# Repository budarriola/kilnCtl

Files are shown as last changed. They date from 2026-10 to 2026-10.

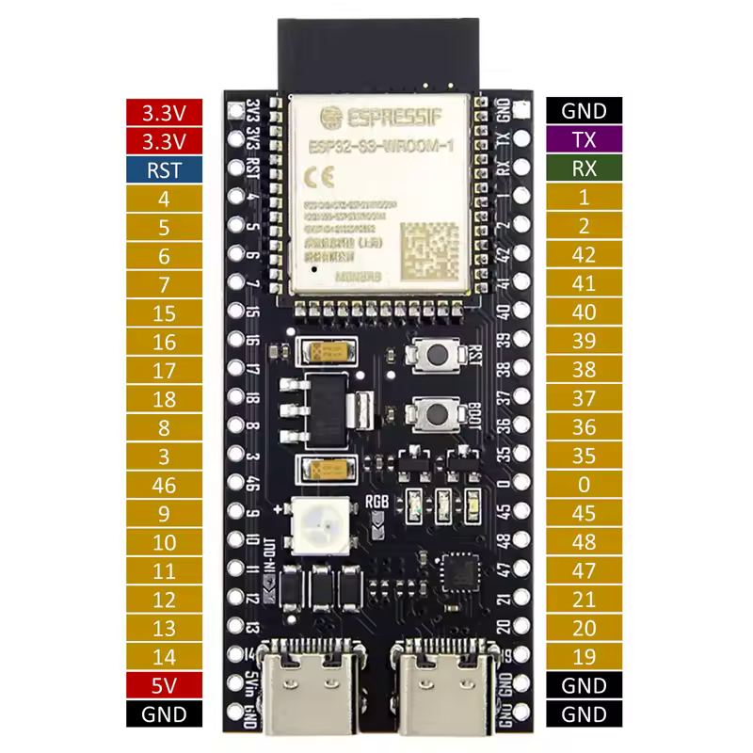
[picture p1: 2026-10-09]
tools/PcTools/src/kilnctrl/assets/pinout.png

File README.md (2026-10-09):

# kilnCtl

> **WARNING: read the [Liability waiver and safety disclaimer](#liability-waiver-and-safety-disclaimer)
> before you build, flash, wire, or power anything from this repository.**
> This is an unfinished, experimental controller for an appliance that runs above
> 1000 °C on mains power. Even where it is believed to be stable, assume it **will**
> start a fire that burns your house down with everyone inside it.

A kiln controller: three KiCad boards, two independent firmwares, and the PC
tooling that drives both.

Heating is commanded by an ESP32-S3 through solid-state relays. A separate
RP2040 watches the same kiln and can cut power through a mechanical pilot relay
that is wired in series with the contactor coil. The two processors talk over an
opto-isolated UART, and the main processor is not allowed to heat unless the
safety processor is answering.

## Start here

**[ROADMAP.md](ROADMAP.md)** is the top-level plan across both processors. It
holds the milestone order and the cross-processor dependencies, and links to the
plan that owns each area. If you do not already know which document covers what
you are about to do, start there.

## Running the regression suite

```
python tools/regression_suite.py
```

One command, every automated gate this repo has, one pass/fail summary and a
non-zero exit on any failure (usable in CI or a pre-commit hook). It runs, in
order: `tools/run_all_checks.ps1` (the mechanical `check_*.ps1` guards, plus
the JS/browser harnesses and the headless-Chrome responsive sweep, which are
themselves wired into that script's discovery); then, in parallel, the KilnFW
and SaftyFW off-target host-test suites and the `tools/PcTools` pytest suite
(its live-bench tests self-skip with no board attached); then,
in parallel, the two target firmware *compiles* (KilnFW over ESP-IDF, SaftyFW
over pico-sdk -- no flashing, ever). One gate failing does not stop the
others; the final summary lists every gate's pass/fail and points at the full
log for anything that failed. See the script's own header comment for why
each stage is grouped and parallelized the way it is.

## Opening this repository

On a fresh clone, run **[`tools/setup.ps1`](tools/setup.ps1)** first — it
discovers where ESP-IDF, clangd and OpenOCD live on this machine and generates
the config files that cannot be committed. Full detail:
[docs/SETUP.md](docs/SETUP.md).

In VS Code, open **`kilnCtl.code-workspace`** rather than the `kilnCtl` folder.
The ESP-IDF extension treats a workspace folder as one project and needs a
`CMakeLists.txt` in it; the repository root does not have one. The workspace file
lists each firmware, `tools/PcTools` and `hardware` as folders in their own right,
and carries the shared tasks.

Shell commands in this repository are written to run from the root, so they carry
a path argument: `idf.py -C firmware/KilnFW build`,
`uv run --project tools/PcTools kilnctrl-gui`.

## Layout

```
hardware/   KiCad projects, shared library, datasheets, LTspice, sourcing
firmware/   KilnFW (ESP32-S3), SaftyFW (RP2040), CommonFW (shared)
tools/      PcTools - GUI and MCP server for both processors
docs/       System-level documents that span hardware and firmware
```

`mykicadMcp/` and `pdfMcp/` both moved under `tools/` 2026-08-28.
The rationale for the split, and what broke during it, is
[docs/REPO_LAYOUT.md](docs/REPO_LAYOUT.md).

## The three boards

| Board | What it is |
|---|---|
| `hardware/mainBoard` | ESP32-S3 controller, SSR drivers, current sense, isolated link, safety RP2040 |
| `hardware/ThermocoupleBoard` | 3-channel MAX31856 daughterboard |
| `hardware/SaftyThermocoupleBoard` | The safety processor's own thermocouple front end |

`Thermocouple.kicad_sch` appears in more than one project as a copy of the same
circuit, so a fix found in one usually applies to the others.

## The two firmwares

- **`firmware/KilnFW`** — ESP-IDF. Thermocouples, PID, profile execution, Wi-Fi
  provisioning, web UI. Partly built, partly verified on hardware; the honest
  ledger is [firmware/KilnFW/docs/PROJECT_STATUS.md](firmware/KilnFW/docs/PROJECT_STATUS.md).
- **`firmware/SaftyFW`** — pico-sdk and FreeRTOS SMP. Independent overheat and
  fault detection, owns the pilot relay. Planned in detail, **not yet built**.
- **`firmware/CommonFW`** — the link contract and its codecs, implemented once
  and linked by both. Also not yet built.

The safety processor's job is to catch faults, not to be sensitive: every trip
has to clear both a magnitude that correct operation cannot reach and a duration
a transient cannot sustain. That reasoning is
[firmware/SaftyFW/docs/SAFETY_MODEL.md](firmware/SaftyFW/docs/SAFETY_MODEL.md).

## Tooling

`tools/PcTools` is one GUI and one MCP server for both processors — serial to
the ESP, the isolated UART or SWD to the Pico, per-processor consoles and log
files. See [tools/PcTools/README.md](tools/PcTools/README.md) for what exists and
[tools/PcTools/TODO.md](tools/PcTools/TODO.md) for what is planned.

`mykicadMcp` is a separate submodule exposing KiCad inspection, sourcing and
autorouting over MCP.

## Bench setup

Programming, debug and console for the RP2040 all go through a Raspberry Pi
Debug Probe: SWD to the DEBUG pads, and the probe's UART bridge on GP16/GP17.
The Pico's own USB is deliberately not used. Wiring is
[firmware/SaftyFW/docs/HARDWARE.md](firmware/SaftyFW/docs/HARDWARE.md) §7b.

## Liability waiver and safety disclaimer

**This project is a work in progress. It is not finished, not certified, and not
safe.** Everything in this repository (schematics, PCB layouts, firmware for both
processors, PC tools, documentation, release images, and any advice in issues or
discussions) is an experimental, hobbyist development effort that is still
changing daily.

**Even where a part of it is believed to be stable, it is not.** Code that has
passed every test in this repository, every bench run, and every review can still
fail in the field. Treat every release, including those marked "stable", as a
pre-release prototype.

**Assume it will burn your house down with everyone inside.** A kiln is a
resistive heater that reaches well above 1000 °C, draws tens of amps from mains
power, and is often left unattended for many hours. A controller fault, a
firmware bug, a stuck or welded relay, a failed thermocouple, a wiring mistake, a
bad update, a power glitch, or a single misread value can leave the elements
energized with nothing to stop them. The likely result is a fire that destroys the
building and kills or seriously injures the people and animals inside it.
Electrocution, burns, toxic fumes, and damage to the kiln, its contents and
nearby property are also likely. Plan as if these outcomes will happen, not as if
they might.

**The safety processor does not make this safe.** The RP2040 safety processor, its
trip guards, the E-stop path, the pilot relay, and every other protective feature
described here are part of the same unfinished, unverified design. They have not
been independently evaluated and must not be relied on to prevent fire, injury or
death. This design does not replace a certified, independent over-temperature
cutoff, a correctly rated contactor, proper overcurrent protection, a
non-combustible installation, working smoke and fire detection, and a person
physically present and watching the kiln.

**No certification.** Nothing here has been tested, listed or approved by UL, CSA,
CE, TÜV, or any other safety or standards body, and nothing here complies with
any electrical, building or fire code. Installing it may break local law, void
your insurance, and void the kiln manufacturer's warranty. Mains wiring must be
done by a licensed electrician where your jurisdiction requires it.

**No warranty.** This project is provided "AS IS" and "AS AVAILABLE", without
warranty of any kind, express or implied. That includes, without limitation, any
warranty of merchantability, fitness for a particular purpose, safety, accuracy,
reliability, non-infringement, or that it will work at all.

**No liability.** To the fullest extent permitted by law, the authors,
contributors, copyright holders, and anyone who distributes this project are not
liable for any claim, damage, injury, death, loss of property, loss of data, loss
of income, or other loss of any kind, whether direct, indirect, incidental,
special, consequential, or punitive, and whether based on contract, tort
(including negligence), strict liability, or any other theory. This holds even if
they were told such loss was possible, and it applies to any use of this project,
any inability to use it, and any failure of it.

**You accept all risk.** By building, flashing, installing, operating, modifying,
or distributing anything from this repository, you agree that you do so entirely
at your own risk, that you are solely responsible for the safety of your
installation and of everyone and everything near it, and that you will indemnify
and hold harmless the authors and contributors against any claim arising from
your use. If you do not accept these terms, do not use this project.

**Not advice.** Nothing in this repository is professional, electrical,
engineering, or legal advice. If any part of this waiver cannot be enforced where
you live, the rest of it still applies.

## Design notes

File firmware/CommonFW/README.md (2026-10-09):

# CommonFW — shared control-interface code

> **Status:** planning · **Last reviewed:** 2026-08-24
> **Keep this file current.** If you change anything this document describes,
> update it in the same commit. If it disagrees with the code, **the code
> wins** — fix this file and say so in the commit message.

The wire between the ESP32-S3 main controller ([`../KilnFW`](../KilnFW)) and
the RP2040 safety processor ([`../SaftyFW`](../SaftyFW)), implemented **once**
and linked into both.

`CommonFW` also hosts a second, independent protocol family here:
**`benchproto`** ([`docs/BENCHPROTO.md`](docs/BENCHPROTO.md),
`include/benchproto/`, `src/benchproto_*.c`) — a hardened, addressed
request/reply protocol (framing, CRC16, retry/dedup, task registration) for
bench/instrument firmwares talking to a PC, extracted from
`firmware/UnitTestFw`'s UART prototype for SimFW's USB-CDC link (SimFW
was removed 2026-08-28, `UnitTestFw` restored in its place; the design
rationale that lived in SimFW's `docs/DESIGN_NOTES.md` sec 4.4/12 went with
it). It shares no code with `kilnlink`
— see `docs/BENCHPROTO.md` sec 1 for why the two look alike but are kept
apart — and is host-tested the same way (`test_benchproto_frame.c`,
`test_benchproto_link.c`, both wired into this file's `CMakeLists.txt`).

**Status: the framing layer exists and is host-tested.** `kilnlink_frame.{c,h}`
+ `kilnlink_crc.c` are written, byte-exact cross-checked against
`tools/PcTools/src/kilnctrl/protocol.py` (the second, already-proven
implementation of this exact envelope) via `test/vectors/frame_vectors.json`,
consumed by both `test/test_frame.c` (built and passing with MSVC via CMake +
Ninja, verified 2026-08-16) and `tools/PcTools/selfcheck.py`. **Framing is now
integrated into both firmwares** (as of 2026-08-18): `KilnFW`'s
`firmware/hwAbstraction/esp/uart/uart_protocol.c` calls `kilnlink_crc16_ccitt_false`/
`kilnlink_stuff` instead of its own copies, proven byte-identical against the
pre-migration implementation (`test/test_uart_protocol_delegate.c`); `SaftyFW`
now has a real CMake project (`firmware/SaftyFW/CMakeLists.txt`,
`add_subdirectory(../CommonFW kilnlink)`) linking `kilnlink` into all three of
its executables, and `link_task.c` calls into several of the payload codecs
directly (see below). Payload-codec migration is still partial — see
"2026-08-19" below and the Completion checklist's Migration section.

**2026-08-19: every command/frame `docs/LINK_PROTOCOL.md` sections 4 and 6 give
a concrete byte layout for now has a codec.** ESP→Pico (sec 4):
`kilnlink_context.{c,h}` (`SAFETY_CMD_PUSH_CONTEXT` 0x07, including
`relay_recent_mask` and the per-zone block), `kilnlink_announce.{c,h}`
(`SAFETY_CMD_ANNOUNCE_VERSION` 0x0F, the compatibility-floor layout),
`kilnlink_ceiling.{c,h}` (`SAFETY_CMD_SET_FIRING_CEILING` 0x09),
`kilnlink_clear_trip.{c,h}` (`SAFETY_CMD_CLEAR_TRIP` 0x0A),
`kilnlink_get_fw_version.{c,h}` (`SAFETY_CMD_GET_FW_VERSION` 0x0B, one byte,
no fields), `kilnlink_set_clock.{c,h}` (`SAFETY_CMD_SET_CLOCK` 0x0C, optional).
Pico→ESP (sec 6): `kilnlink_status.{c,h}` (Frame A, `SAFETY_CMD_GET_STATUS`
0x01, the existing 23-byte layout), `kilnlink_diag.{c,h}` (Frame B,
`SAFETY_CMD_DIAG` 0x08), `kilnlink_trip.{c,h}` (Frame D,
`SAFETY_CMD_TRIP_EVENT` 0x0D), `kilnlink_power.{c,h}` (Frame E,
`SAFETY_CMD_POWER` 0x0E). All ten are host-tested (one `test_<name>.c` each,
MSVC+CMake+Ninja, all passing as of 2026-08-19 -- 13 host test binaries
total including `test_frame`/`test_fuzz`/`test_uart_protocol_delegate`) with
byte-exact vectors in `test/vectors/`, and as of 2026-08-19 every one of
those vector manifests is also consumed by `tools/PcTools/selfcheck.py`
(`commonfw_payload_vector_checks()`, against the new pure-Python encoder/decoder pair that lives there
(`kilnctrl/kilnlink_codec.py`) -- not just `frame_vectors.json` as before.
`kilnlink_codec.py` is encode-only: nothing in `pc_tools` decodes these
frames yet, so there is no real caller to justify a decode side (see that
module's own docstring).

**2026-08-20: three more codecs close the CT-calibration gap** `firmware/
SimFW/tools/ct_calibration/README.md` documented: `kilnlink_set_ct_cal.{c,h}`
(`SAFETY_CMD_SET_CT_CAL` 0x19, ESP→Pico, sets one channel's CT amps
gain/offset), `kilnlink_get_ct_cal.{c,h}` (`SAFETY_CMD_GET_CT_CAL` 0x1A,
ESP→Pico, one byte, no fields) and `kilnlink_ct_cal.{c,h}` (`SAFETY_CMD_
CT_CAL`, same 0x1A id as the request, Pico→ESP reply, 28 bytes, all three
channels). Host-tested (`test_set_ct_cal.c`/`test_get_ct_cal.c`/
`test_ct_cal.c`, hand-computed byte-exact vectors inline rather than in
`test/vectors/` -- no `tools/PcTools/selfcheck.py` cross-check exists yet
for these three; that PC-side integration, and the PC-side sender for
`SET_CT_CAL` itself, are still open. The consumer is `firmware/SaftyFW/src/
tasks/link_task.c` (`link_task_handle_set_ct_cal()`/`_get_ct_cal()`/
`send_ct_cal()`) against `firmware/SaftyFW/src/config_store.{c,h}`'s `ct_cal`
record and `firmware/SaftyFW/src/ct_amps_cal.{c,h}`'s pure apply logic.

**2026-08-21: five codecs for `docs/COMMISSIONING.md` sec 2's commissioning
family (ids 0x1B-0x1F).** Codecs and host tests only -- no consumer wiring in
either firmware yet, same as `SET_CT_CAL` when it landed.
`kilnlink_set_log_level.{c,h}` (`SAFETY_CMD_SET_LOG_LEVEL` 0x1B, ESP→Pico, 2
bytes, opaque `LOG_LEVEL_*` byte). `kilnlink_set_param.{c,h}`
(`SAFETY_CMD_SET_PARAM` 0x1C, ESP→Pico, `param_id` u16 + type tag + a
variable-length value -- stages only, nothing reaches flash from this frame
alone). `kilnlink_commit_config.{c,h}` (`SAFETY_CMD_COMMIT_CONFIG` 0x1D,
ESP→Pico, one byte, no fields -- validates the staged set as a whole and
writes it; that validation is `SaftyFW`'s, not this codec's).
`kilnlink_get_param.{c,h}` / `kilnlink_param.{c,h}` (`SAFETY_CMD_GET_PARAM`/
`PARAM`, both 0x1E, request/reply sharing an id per the `GET_CT_CAL`/`CT_CAL`
convention; the reply carries an explicit `found` byte so an id one side
doesn't recognise is named in the reply rather than failing the whole
exchange). `kilnlink_get_config_page.{c,h}` / `kilnlink_config_page.{c,h}`
(`SAFETY_CMD_GET_CONFIG_PAGE`/`CONFIG_PAGE`, both 0x1F, bulk read of packed
`(id, type, value)` triples, one page per frame).

**2026-08-24: the three shared request/reply ids above were split apart**
(`KILNLINK_PROTOCOL_VERSION` 6 -> 7): `GET_CT_CAL` moved to `0x22`,
`GET_PARAM` to `0x23`, `GET_CONFIG_PAGE` to `0x24` -- their replies
(`CT_CAL`/`PARAM`/`CONFIG_PAGE`) keep `0x1A`/`0x1E`/`0x1F` unchanged. A
shared id structurally blocks a length-different refusal reply (neither a
bare request nor the fixed-size success reply), which is exactly what was
blocking `firmware/KilnFW/App/drivers/bridge/uart_bridge.c`'s SAFETY task from ever
telling the PC "driver error" for `GET_CT_CAL` -- see
`docs/LINK_PROTOCOL.md`'s "Request/reply ids must never be shared" rule for
the reusable lesson. `GET_FW_VERSION`/Frame C still shares its id
deliberately -- it sits in the frozen `0x00`-`0x0F` floor, where a refusal
is never needed.

All five share a new type-tag helper, `kilnlink_param_value.{c,h}`
(`KILNLINK_PARAM_TYPE_BOOL/U8/U16/F32`, 1/1/2/4 bytes) -- a small closed tag
set rather than a length-prefixed blob, so a value whose declared type this
build doesn't recognise is a decode `ERR_BAD_TYPE`, never a guess at how many
bytes follow. `kilnlink_config_page_pack()` greedily packs `(id, value)`
pairs into a page until the next one would not fit in the 253-byte payload
cap, then reports `more = 1` if entries remain -- the caller re-invokes with
the leftover slice and the next page index. Host-tested (`test_set_log_
level.c`, `test_param_value.c`, `test_set_param.c`, `test_commit_config.c`,
`test_get_param.c`, `test_param.c`, `test_get_config_page.c`,
`test_config_page.c`): round trips for every type tag, byte-exact vectors,
and the hostile-input set (short/over-long/truncated-mid-value/bad-type-tag
frames, plus `CONFIG_PAGE`'s entry_count-too-large and trailing-garbage
cases and length sweeps that assert no other length ever decodes OK). No
`tools/PcTools/selfcheck.py` cross-check exists yet for these five, same gap
`SET_CT_CAL`'s entry above notes.

**Wiring status, same day (2026-08-19):** most of
these codecs are still codec-only, not called from either firmware's real
send/receive dispatch -- see Migration below -- but two are now genuine
exceptions. `ANNOUNCE_VERSION` (0x0F) is wired on both ends:
`SaftyFW`'s `link_task.c` decodes inbound frames via
`kilnlink_announce_decode()`, and `KilnFW`'s `safety_link.c` builds outbound
ones via `kilnlink_announce_encode()` (its `components/kilnlink/CMakeLists.txt`
now compiles `kilnlink_announce.c` to make that possible -- still a subset of
what `SaftyFW`'s CMake links, see the ESP-IDF component wrapper item below).
`CLEAR_TRIP` (0x0A) is wired on both ends: `SaftyFW`'s
`link_task.c` decodes it via `kilnlink_clear_trip_decode()` and enforces the
refusal rules `docs/LINK_PROTOCOL.md` section 4 describes (refuses if nothing is
currently tripped, refuses if the wire `trip_mask` doesn't match the
latched one); `KilnFW`'s `safety_link_commands.c` builds it via
`kilnlink_clear_trip_encode()`.

## Why this exists

The link is a contract between two independently-built firmwares. Implemented
twice, it drifts — and it drifts silently, because a framing or field-offset
mismatch does not fail loudly, it delivers a plausible wrong number.

This project already has evidence of exactly that failure mode: the isolated
link's wire direction was documented backwards in `firmware/KilnFW/docs/SAFETY_LINK.md`
for months, because the description lived inside one of the two implementations
and read as an implementation note rather than as a contract with a second party
(`firmware/SaftyFW/docs/HARDWARE.md` §1).

So: **one definition of the frame layouts, one encoder, one decoder, one set of
test vectors, and the protocol document lives here** rather than inside either
firmware.

## Layout

```
firmware/CommonFW/
├─ README.md                       ← this file
├─ docs/
│  ├─ LINK_PROTOCOL.md             ← THE kilnlink contract. Owned here, not by either firmware
│  └─ BENCHPROTO.md                ← THE benchproto spec (separate protocol family, see "Layout" below)
├─ include/benchproto/
│  ├─ benchproto_version.h         ← BENCHPROTO_PROTOCOL_VERSION, the single source
│  ├─ benchproto_frame.h           ← delimiter/stuffing/CRC framing (independent of kilnlink_frame.h)
│  └─ benchproto_link.h            ← retry/dedup + addressable-task-registration model
├─ include/kilnlink/
│  ├─ kilnlink_version.h           ← KILNLINK_PROTOCOL_VERSION, the single source
│  ├─ kilnlink_bytes.h             ← shared LE encode/decode helpers
│  ├─ kilnlink_frame.h             ← delimiter/stuffing/CRC framing
│  ├─ kilnlink_context.h           ← ESP → Pico, SAFETY_CMD_PUSH_CONTEXT (0x07)
│  ├─ kilnlink_announce.h          ← ESP → Pico, SAFETY_CMD_ANNOUNCE_VERSION (0x0F)
│  ├─ kilnlink_ceiling.h           ← ESP → Pico, SAFETY_CMD_SET_FIRING_CEILING (0x09)
│  ├─ kilnlink_clear_trip.h        ← ESP → Pico, SAFETY_CMD_CLEAR_TRIP (0x0A)
│  ├─ kilnlink_get_fw_version.h    ← ESP → Pico, SAFETY_CMD_GET_FW_VERSION (0x0B)
│  ├─ kilnlink_set_clock.h         ← ESP → Pico, SAFETY_CMD_SET_CLOCK (0x0C)
│  ├─ kilnlink_status.h            ← Pico → ESP, Frame A, SAFETY_CMD_GET_STATUS (0x01)
│  ├─ kilnlink_diag.h              ← Pico → ESP, Frame B, SAFETY_CMD_DIAG (0x08)
│  ├─ kilnlink_trip.h              ← Pico → ESP, Frame D, SAFETY_CMD_TRIP_EVENT (0x0D)
│  ├─ kilnlink_power.h             ← Pico → ESP, Frame E, SAFETY_CMD_POWER (0x0E)
│  ├─ kilnlink_set_config.h        ← ESP → Pico, SAFETY_CMD_SET_CONFIG (0x16)
│  ├─ kilnlink_set_ct_cal.h        ← ESP → Pico, SAFETY_CMD_SET_CT_CAL (0x19)
│  ├─ kilnlink_get_ct_cal.h        ← ESP → Pico, SAFETY_CMD_GET_CT_CAL (0x22, own id since v7)
│  ├─ kilnlink_ct_cal.h            ← Pico → ESP, SAFETY_CMD_CT_CAL (0x1A, reply)
│  ├─ kilnlink_set_log_level.h     ← ESP → Pico, SAFETY_CMD_SET_LOG_LEVEL (0x1B)
│  ├─ kilnlink_param_value.h       ← shared type-tag + value codec (BOOL/U8/U16/F32)
│  ├─ kilnlink_set_param.h         ← ESP → Pico, SAFETY_CMD_SET_PARAM (0x1C)
│  ├─ kilnlink_commit_config.h     ← ESP → Pico, SAFETY_CMD_COMMIT_CONFIG (0x1D)
│  ├─ kilnlink_get_param.h         ← ESP → Pico, SAFETY_CMD_GET_PARAM (0x23, own id since v7)
│  ├─ kilnlink_param.h             ← Pico → ESP, SAFETY_CMD_PARAM (0x1E, reply)
│  ├─ kilnlink_get_config_page.h   ← ESP → Pico, SAFETY_CMD_GET_CONFIG_PAGE (0x24, own id since v7)
│  ├─ kilnlink_config_page.h       ← Pico → ESP, SAFETY_CMD_CONFIG_PAGE (0x1F, reply)
│  └─ kilnlink_fw_version.h        ← Pico → ESP, Frame C, SAFETY_CMD_FW_VERSION (0x0B, reply)
│  (no `kilnlink_ids.h` or `kilnlink_port.h` yet — see the Completion checklist)
├─ src/
│  ├─ kilnlink_crc.c    kilnlink_frame.c     kilnlink_context.c
│  ├─ kilnlink_announce.c  kilnlink_ceiling.c  kilnlink_clear_trip.c
│  ├─ kilnlink_get_fw_version.c  kilnlink_set_clock.c
│  ├─ kilnlink_status.c  kilnlink_diag.c  kilnlink_trip.c  kilnlink_power.c
│  ├─ kilnlink_set_config.c  kilnlink_set_ct_cal.c  kilnlink_get_ct_cal.c  kilnlink_ct_cal.c
│  └─ kilnlink_set_log_level.c  kilnlink_param_value.c  kilnlink_set_param.c
│     kilnlink_commit_config.c  kilnlink_get_param.c  kilnlink_param.c
│     kilnlink_get_config_page.c  kilnlink_config_page.c  kilnlink_fw_version.c
├─ src/benchproto_crc.c  src/benchproto_frame.c  src/benchproto_link.c
├─ test/
│  ├─ test_frame.c  test_fuzz.c  test_uart_protocol_delegate.c
│  ├─ test_context.c  test_announce.c  test_ceiling.c  test_clear_trip.c
│  ├─ test_get_fw_version.c  test_set_clock.c
│  ├─ test_status.c  test_diag.c  test_trip.c  test_power.c
│  ├─ test_set_config.c  test_set_ct_cal.c  test_get_ct_cal.c  test_ct_cal.c
│  ├─ test_set_log_level.c  test_param_value.c  test_set_param.c  test_commit_config.c
│  ├─ test_get_param.c  test_param.c  test_get_config_page.c  test_config_page.c
│  ├─ test_fw_version.c
│  ├─ test_benchproto_frame.c  test_benchproto_link.c
│  └─ vectors/                     ← shared byte-exact test vectors, see below
│     (kilnlink's `*_vectors.json` plus benchproto_frame_vectors.json)
└─ CMakeLists.txt                  ← builds both the `kilnlink` and `benchproto` targets
```

## Rules for code in here

These are what make the same source usable from ESP-IDF, pico-sdk and a host
test binary. **A violation of any of them is a build break, not a style note.**

1. **Freestanding C11.** `stdint.h`, `stdbool.h`, `stddef.h`, `string.h`. Nothing
   else — no ESP-IDF, no pico-sdk, no FreeRTOS, no POSIX.
2. **No allocation, ever.** Every function writes into a caller-supplied buffer
   with a caller-supplied length.
3. **No I/O and no time.** Encoders and decoders are pure functions. Timestamps
   arrive as arguments. This is what makes them host-testable and what keeps the
   safety processor's guard path free of anything that can block.
4. **No global mutable state.** Every function is reentrant; both firmwares call
   these from more than one task.
5. **Explicit byte packing.** No `__attribute__((packed))` structs cast onto the
   wire, no `memcpy` of a struct, no bitfields. Serialize field by field, little
   endian, by hand. Both targets happen to be little-endian; relying on that
   makes the host tests unable to catch a layout mistake.
6. **Every decoder is bounds-checked and returns a status.** A payload is
   untrusted input from another processor across an isolated link. A decoder
   that can be made to read past its buffer by a corrupt length byte is a bug in
   the component that must not have bugs.
7. **`-Wall -Wextra -Werror`, and it must compile clean under all three
   toolchains** — xtensa-gcc, arm-none-eabi-gcc, MSVC.
8. **No `assert()` that survives into release.** A decoder returns an error; it
   does not abort the safety processor.

## What is *not* shared

| Stays in `KilnFW` | Why |
|---|---|
| `uart_owner.c` | ESP-IDF UART driver, ring buffers, event task |
| `uart_protocol.c`'s transport half | ACK/NACK, retry, dedup, task registry, FreeRTOS queues. The Pico deliberately has none of this (`docs/LINK_PROTOCOL.md` §2) |
| `uart_task_ids.h`'s PC-link half | THERMO/IO/DISPLAY/CONTROL/PROFILES/AUTOTUNE/WIFI are ESP↔PC only and never cross the barrier |
| `uart_log_bridge.c` | ESP-only |

| Stays in `SaftyFW` | Why |
|---|---|
| `uart_owner.c` | pico-sdk UART, non-blocking TX ring |
| `link_task.c` | Task plumbing, snapshot publication |
| Everything in `safety_guards.c` | Policy, not protocol |

**The split is transport vs. contract.** Bytes-on-a-wire and how they are moved
are each firmware's own problem; what the bytes *mean* is shared.

## Integration

### `SaftyFW` (pico-sdk + CMake)

```cmake
add_subdirectory(../CommonFW kilnlink)
target_link_libraries(SaftyFW PRIVATE kilnlink)
```

### `KilnFW` (ESP-IDF component)

Add a thin `components/kilnlink/CMakeLists.txt` wrapper:

```cmake
idf_component_register(SRCS ${KILNLINK_SRCS}
                       INCLUDE_DIRS ${KILNLINK_DIR}/include)
```

pointing at `../../CommonFW`. **`uart_protocol.c` then deletes its own CRC and
byte-stuffing and calls `kilnlink_frame_*` instead.** This is a refactor of
working, hardware-verified code, so it needs the round-trip tests below passing
against the *existing* implementation's output before the old code is removed.

### `pc_tools` — the third implementation

`tools/PcTools/src/kilnctrl/protocol.py` implements this same framing in
Python and cannot link C. It is the reason for `test/vectors/`.

## Test vectors are the mechanism that keeps three implementations honest

`test/vectors/` holds byte-exact encode/decode pairs — a JSON manifest plus the
raw frames — that **all three** implementations run against:

- The C tests decode each vector and assert the decoded fields, then re-encode
  and assert byte equality.
- `pc_tools`' test suite loads the same manifest.
- A vector is added for **every** frame type and for every edge case that has
  ever caused a bug.

Include hostile vectors, not just valid ones: truncated frames, a length byte
larger than the payload, an unterminated escape at the end of a buffer, a
delimiter inside a payload, wrong CRC, `zone_count` beyond the array, NaN and
infinity in every float field.

This is cheaper than a code generator and catches the failure that actually
happens — one implementation updated, the other two not.

## Versioning

`KILNLINK_PROTOCOL_VERSION` lives in `kilnlink_version.h` and is the source of
truth for the **ESP<->Pico isolated safety link only**. `KilnFW`'s
`UART_PROTOCOL_VERSION` (`App/drivers/common/uart_task_ids.h`) is the **PC<->ESP
link**'s own, independent version — the two links are different contracts and
version separately.

From 2026-08-17 to 2026-08-24 `UART_PROTOCOL_VERSION` was a plain alias of
`KILNLINK_PROTOCOL_VERSION` rather than a second number. That alias bit real
hardware three times: a bump driven purely by the isolated link's own contract
(most notably 2026-08-23's Frame A `tx_dropped_sat` addition, which touched
nothing on the PC link) silently dragged the PC link's version along with it,
and `devices.FirmwareVersion.compatible` in `pc_tools` — a hard equality gate —
then refused every PC command against a board that, from the PC link's own
point of view, had not changed at all. The alias is gone; the two constants
are independent literals again and must stay that way.
`tools/check_uart_version_independence.ps1` (repo root) is the CI grep that
enforces it.

Bump each one when **its own** link's contract would break a peer running the
old value: renumbering an id, changing a payload layout or length, or changing
the envelope. Do not bump for comments or internal refactors, and do not bump
one because the other moved. It is a human judgement call, deliberately not a
hash of the file — the reasoning in
`firmware/KilnFW/App/drivers/common/uart_task_ids.h:8-20` applies unchanged and should
be carried over with each constant.

---

## Completion checklist

Tick these as they land. Phase numbers refer to [`../SaftyFW/TODO.md`](../SaftyFW/TODO.md).

**Structure**
- [x] `firmware/CommonFW/` created with the layout above (2026-08-16; `docs/`,
      `include/kilnlink/`, `src/`, `test/`, `test/vectors/` all exist —
      `kilnlink_context.h`/`kilnlink_status.h` added 2026-08-18, see Codecs.
      `kilnlink_ids.h` deliberately not created — see Contract, "Won't do")
- [x] `CMakeLists.txt` producing a `kilnlink` target consumable by pico-sdk
      (standard `add_library` + `target_include_directories`). **Now actually
      linked into a pico-sdk build**: `firmware/SaftyFW/CMakeLists.txt` has
      `add_subdirectory(../CommonFW kilnlink)` and links it into all three of
      `SaftyFW`'s executables (`SaftyFW`/`SaftyFW_slotA`/`SaftyFW_slotB`)
- [x] ESP-IDF component wrapper in `firmware/KilnFW/components/kilnlink/`
      (2026-08-16). Auto-discovered under `firmware/KilnFW/components/` —
      ESP-IDF's default search path, no `EXTRA_COMPONENT_DIRS` edit needed.
      `App/drivers/CMakeLists.txt` lists it in `REQUIRES` so `idf.py build`
      compiles it. Framing is now called from `uart_protocol.c` and
      `kilnlink_announce` from `safety_link.c` (see Migration); it still
      compiles only a subset of the codecs `SaftyFW`'s CMake links
      (`kilnlink_crc.c`, `kilnlink_frame.c`, `kilnlink_context.c`,
      `kilnlink_announce.c` — added 2026-08-19 — not the rest)
- [x] Builds clean under xtensa-gcc, arm-none-eabi-gcc and MSVC at `-Wall -Wextra -Werror`.
      **MSVC verified** (cl.exe via CMake+Ninja, `/W4 /WX`), **xtensa-gcc
      verified** (`idf.py -C firmware/KilnFW build`, real callers now exist so
      nothing is stripped by `--gc-sections`), and **arm-none-eabi-gcc
      verified**: `SaftyFW`'s real CMake project (`add_subdirectory(../CommonFW
      kilnlink)`) builds `kilnlink` clean into all three of its executables

**Contract**
- [x] `docs/LINK_PROTOCOL.md` moved here from `firmware/SaftyFW/docs/` and cross-links updated
      (already done before this session — confirmed 2026-08-16, no stale
      duplicate remains under `firmware/SaftyFW/docs/`)
- [x] `kilnlink_version.h` created (2026-08-16). `KilnFW`'s `UART_PROTOCOL_VERSION`
      (`App/drivers/common/uart_task_ids.h`) was a real alias of `KILNLINK_PROTOCOL_VERSION`
      from 2026-08-17 to 2026-08-24; that alias is now gone (see "Versioning"
      above) — the two are independent literals again, `UART_PROTOCOL_VERSION`
      frozen at 7, `KILNLINK_PROTOCOL_VERSION`/`KILNLINK_MIN_COMPATIBLE` at 7/5.
      This line used to describe the alias as the intended end state; it
      wasn't, and this entry was stale until 2026-08-24.
- [x] **Won't do** — `kilnlink_ids.h` as a shared-ids header consumed by
      `uart_task_ids.h`. Investigated 2026-08-24 (see `SaftyFW/TODO.md`'s
      matching entry): every `SAFETY_CMD_*` in `uart_task_ids.h` that matches
      a `KILNLINK_*_CMD` value is a *documented, deliberate* literal mirror,
      not an oversight —
        - Several of them are genuinely dual-purpose: `uart_bridge.c` dispatches
          real PC→ESP commands (`SAFETY_CMD_CLEAR_TRIP`, `SET_CONFIG`,
          `ROLLBACK`, `SET_CT_CAL`, `GET_CT_CAL`, …) on these exact values,
          "doubling additively" as PC-link subcommands on
          `UART_TASK_ID_SAFETY` — they are not "PC-link ids left behind" vs.
          "shared ids," they are both at once by design.
        - The rest (`SAFETY_CMD_PUSH_CONTEXT`, `SET_LOG_LEVEL`, `SET_PARAM`,
          `COMMIT_CONFIG`, `GET_PARAM`/`PARAM`, `GET_CONFIG_PAGE`/`CONFIG_PAGE`,
          `COMMIT_CONFIG_REJECTED`, `ANNOUNCE_REBOOT`) are redeclared purely so
          `uart_task_ids.h` stays "the one place every `SAFETY_CMD_*`
          subcommand on this wire is enumerated" (its own doc comments, e.g.
          line ~916) — the codec header's `KILNLINK_*_CMD` is named in the
          same comment as the actual authority.
        - `SaftyFW/src/tasks/link_frame.h` makes the identical choice for the
          identical reason: `LINK_FRAME_CLEAR_TRIP_CMD`/`SET_CONFIG_CMD`/
          `ROLLBACK_CMD`/`SET_CT_CAL_CMD` are redeclared as local dispatch
          literals "rather than pulling the kilnlink codec header into this
          file's own namespace," even though `link_task.c` in the same
          firmware already includes and calls the kilnlink codecs directly.
          This is an established, repo-wide convention — a dispatch/enumeration
          header states its own ids as literals with a cross-reference comment
          to the codec header that owns the value, instead of `#include`-ing
          the codec just to reach one macro.
      Collapsing these into a shared `kilnlink_ids.h` would reverse a
      convention both firmwares already apply on purpose, without fixing any
      actual drift (nothing has ever gone out of sync — SaftyFW's own
      duplicate is unmoved evidence this pattern is stable), and does not
      cleanly separate into "shared" vs. "PC-link" as the item's title
      assumed. No code changed for this item; `check_uart_version_independence.ps1`
      still passes (it is unaffected either way — it only ever checked
      `UART_PROTOCOL_VERSION`, not these subcommand ids).

**Codecs**
- [x] `kilnlink_frame.{c,h}` — delimiter, stuffing, CRC16/CCITT-FALSE. Done 2026-08-16
- [x] `kilnlink_context.{c,h}` — ESP → Pico, `SAFETY_CMD_PUSH_CONTEXT` (0x07,
      `LINK_PROTOCOL.md` sec 4). 2026-08-18
- [x] `kilnlink_announce.{c,h}` — ESP → Pico, `SAFETY_CMD_ANNOUNCE_VERSION`
      (0x0F, sec 4, compatibility-floor layout). 2026-08-18
- [x] `kilnlink_ceiling.{c,h}` — ESP → Pico, `SAFETY_CMD_SET_FIRING_CEILING`
      (0x09, sec 4). 2026-08-19
- [x] `kilnlink_clear_trip.{c,h}` — ESP → Pico, `SAFETY_CMD_CLEAR_TRIP`
      (0x0A, sec 4). 2026-08-19
- [x] `kilnlink_get_fw_version.{c,h}` — ESP → Pico, `SAFETY_CMD_GET_FW_VERSION`
      (0x0B, sec 4, one byte, no fields). 2026-08-19
- [x] `kilnlink_set_clock.{c,h}` — ESP → Pico, `SAFETY_CMD_SET_CLOCK` (0x0C,
      sec 4, optional). 2026-08-19
- [x] `kilnlink_status.{c,h}` — Pico → ESP Frame A, `SAFETY_CMD_GET_STATUS`
      (0x01, sec 6, the existing 23-byte layout). 2026-08-18. **2026-08-24:**
      updated for protocol 5→6's optional 24th byte (`tx_dropped_sat`,
      `KILNLINK_STATUS_LEN_V2`) — decode accepts either 23 or 24 bytes,
      encode emits 24 iff the caller sets `has_tx_dropped`, mirroring
      `link_frame_pack_status()`'s own negotiation. `has_tx_dropped` is
      explicit on `kilnlink_status_t` so "peer never sent this" is never
      confused with a real `tx_dropped_sat == 0`. Still latent: nothing
      calls `kilnlink_status_decode`/`_encode` yet (see Migration)
- [x] `kilnlink_inject_tc.{c,h}` — ESP → Pico, `SAFETY_CMD_INJECT_TC`
      (0x21, sec 4, synthetic thermocouple injection gated by
      `safety_tc_installed == 0` on the receiving side). Codec existed
      already; it was the only payload codec with no host test until
      2026-08-24 (`test_inject_tc.c`, 9 cases including a valid=0 "codec
      does not editorialize" check and bit-exact NaN/Inf round trips)
- [x] `kilnlink_diag.{c,h}` — Pico → ESP Frame B, `SAFETY_CMD_DIAG` (0x08, sec 6). 2026-08-18
- [x] `kilnlink_trip.{c,h}` — Pico → ESP Frame D, `SAFETY_CMD_TRIP_EVENT` (0x0D, sec 6). 2026-08-18
- [x] `kilnlink_power.{c,h}` — Pico → ESP Frame E, `SAFETY_CMD_POWER` (0x0E, sec 6). 2026-08-18
- [x] Every `docs/LINK_PROTOCOL.md` sec 4/6 frame with a concrete byte layout
      now has a codec (2026-08-19) -- all ten listed above, plus framing.
      Nothing is wired into either firmware's real send/receive dispatch
      (`uart_protocol.c` on `KilnFW`, `link_task.c` on `SaftyFW`) -- that
      remains separate Migration work, matching how `kilnlink_diag`/
      `kilnlink_trip` already landed codec-only
- [x] Every decoder bounds-checked and returning a status (`kilnlink_frame_decode`/
      `kilnlink_unstuff` and every `kilnlink_<name>_decode` above)
- [x] No allocation, no I/O, no globals — verified by review, not assumed

**Tests**
- [x] Host test binary, all frame types, round-trip byte equality
      (`test/test_frame.c`, MSVC + CMake + Ninja + CTest, 14 checks, all
      passing 2026-08-16)
- [x] Hostile vectors: truncated, over-long length, bad CRC, out-of-range
      counts. **Unterminated escape**: kilnlink itself checks it
      (`KILNLINK_FRAME_ERR_UNTERMINATED_ESC`); `pc_tools`' one-shot `unstuff()`
      does not by design (see the vector's own note in the manifest) — a real,
      documented difference, not an oversight. **NaN/Inf floats**: covered by
      `kilnlink_context`/`kilnlink_status`/`kilnlink_power`'s own vectors
- [x] `test/vectors/` manifest created for every codec above (one
      `<name>_vectors.json` each, `frame_vectors.json` for framing) --
      13 host test binaries total as of 2026-08-19 (`ctest`, all passing)
- [x] `pc_tools` test suite consuming every manifest above, not just
      `frame_vectors.json` (2026-08-19, `selfcheck.py`'s
      `commonfw_vector_checks()` for the framing layer plus the new
      `commonfw_payload_vector_checks()` -- against the new pure-Python
      `tools/PcTools/src/kilnctrl/kilnlink_codec.py` -- for every payload
      codec; fixed a pre-existing invalid-JSON bug in `status_vectors.json`'s
      `too_short` hostile vector found while wiring this up, a stray Python
      slice expression `[:-2]` left in the JSON literal rather than the
      sliced string)
- [x] Fuzz harness over the decoders. Done 2026-08-16: `test/test_fuzz.c`,
      seeded xorshift32 (deterministic/reproducible), both uniform-random and
      structurally-biased garbage (real delimiter/escape/type bytes dropped
      at random positions), every length 0 through past the largest legal
      frame, ~800K inputs against both `kilnlink_frame_decode` and
      `kilnlink_unstuff` -- asserts only "did not crash or hang", passing.
      Not coverage-guided (no libFuzzer/AFL) -- good enough to catch an
      out-of-bounds read or infinite loop, not a substitute for one if this
      code ever needs deeper scrutiny.
      Extended 2026-09-04 (`test/test_fuzz_payloads.c`) to the other 27
      decoders -- every payload codec one layer above the framing pair
      above (context/status/power/announce/diag/trip/ceiling/clear_trip/
      set_config/rollback/get_fw_version/set_clock/announce_reboot/
      set_ct_cal/get_ct_cal/ct_cal/set_log_level/set_param/commit_config/
      commit_config_rejected/inject_tc/get_param/param/get_config_page/
      config_page/rollback_result/fw_version). Same fixed-seed-xorshift32
      determinism, plus a real fixed corpus per decoder (built from that
      decoder's own `_encode()`/`_pack()`: a valid frame bit-flipped at
      every byte, truncated at every offset, and padded with unaccounted
      trailing bytes) and an assertion stronger than "did not crash": a
      truncated or length-lied-about copy of a valid frame must never
      decode OK. Sanitizers confirmed available on this MSVC install
      (`/fsanitize=address` via `test/run_fuzz_payloads_asan.ps1`, opt-in,
      ASan-clean) though not the CI default; canary-guarded output structs
      stand in as the explicit-bounds-assertion fallback for the default
      `cl` build. Negative-tested by deliberately dropping
      `kilnlink_announce_decode()`'s final length check -- the harness
      failed loud, named the decoder, and named the exact truncation that
      broke it; reverted clean. Wired into
      `firmware/SaftyFW/test/build_host_tests.ps1` as CI. Full writeup:
      `firmware/SaftyFW/docs/GUARD_TEST_MATRIX.md`'s "Fuzz over every
      decoder" row.

**Migration**
- [x] `KilnFW`'s `uart_protocol.c` delegating framing/CRC to `kilnlink_frame`
      (2026-08-18): `firmware/hwAbstraction/esp/uart/uart_protocol.c` calls
      `kilnlink_crc16_ccitt_false`/`kilnlink_stuff` instead of its own copies.
      `firmware/UnitTestFw`'s fork was a stale mirror, never migrated; moot
      now, since `UnitTestFw` was decommissioned and deleted wholesale
      (SimFW is its replacement — see `firmware/SimFW/docs/DESIGN_NOTES.md`
      sec 12), so its allowlist entry below is gone with it
- [x] Round-trip proven against the *pre-refactor* implementation's output before old code is deleted
      (`test/test_uart_protocol_delegate.c`, known vectors + 528 fuzz cases)
- [x] `SaftyFW` linking `kilnlink` with no duplicated protocol code —
      `firmware/SaftyFW/CMakeLists.txt` has a real
      `add_subdirectory(../CommonFW kilnlink)` and links `kilnlink` into all
      three of its executables (`SaftyFW`/`SaftyFW_slotA`/`SaftyFW_slotB`);
      `link_task.c` calls into the framing layer plus the
      `diag`/`trip`/`power`/`clear_trip`/`announce` codecs
- [x] `grep` check in CI: no CRC or stuffing implementation outside `CommonFW`
      (`tools/check_no_duplicate_crc.ps1`, 2026-08-18) — not registered in any
      CI pipeline yet (none exists for it to join), and scoped to an explicit
      allowlist of the one pre-migration copy still in the tree (`pc_tools`'
      `protocol.py` mirror). `KilnFW`'s `uart_protocol.c` mirror under
      `UnitTestFw` dropped off the allowlist when `UnitTestFw` was deleted
      wholesale (2026-08-23)
- [ ] Payload codecs (`context`/`ceiling`/`get_fw_version`/`set_clock`/
      `status`/`diag`/`trip`/`power`) wired into either firmware's real
      send/receive dispatch — most are still codec-only. `announce` and
      `clear_trip` are exceptions: both are wired both ways
      (`clear_trip` send side: `KilnFW`'s `safety_link_commands.c`). See the 2026-08-19 note above for the exact
      state of each
- [x] **Frame C (`SAFETY_CMD_FW_VERSION`, §6) now has a `CommonFW` codec**
      (2026-09-01): `kilnlink_fw_version.{c,h}` — same layout as
      `kilnlink_announce.{c,h}` (both are the compatibility-floor's mirror
      pair, sharing wire id `0x0B` deliberately, see §4's "Request/reply ids
      must never be shared" rule for why this one pair is exempt), extended
      past `boot_id` with `config_version` and `config_crc`. Host-tested
      (`test_fw_version.c`, 12 checks: round trip, byte-exact vectors in
      `test/vectors/fw_version_vectors.json`, and the hostile-input set —
      too-short, wrong command byte, commit/datetime length fields that
      claim more bytes than the buffer actually holds, a declared string
      length past this codec's own cap, and a regression guard against the
      exact failure class commit ca472fb fixed elsewhere in this repo: a
      decoder that reads `min(declared_len, cap)` out of a buffer shorter
      than that). Every one of those hostile cases was proven to fail
      red by mutation (removing the length-prefix bounds check, flipping
      `protocol_version`'s encode to big-endian, and dropping `config_crc`
      from the encoder each turned green tests red before the mutation was
      reverted) — this is not a codec that merely runs, it is one whose
      tests can prove a defect.

      **Drift now pinned by host tests (2026-10-07):** both sides are byte-compared
      against this codec -- `SaftyFW/test/test_link_frame_wire.c`
      (`test_fw_version_pack_matches_commonfw_codec`: `link_frame_pack_fw_version()`
      vs `kilnlink_fw_version_encode()`, byte-identical over empty, 1-byte,
      max-length (64+32) and endianness-probe inputs, plus the same undersized-buffer
      refusal) and `KilnFW/App/test/test_safety_link_compile.c`
      (`test_fw_version_parse_matches_commonfw_codec`: `safety_parse_fw_version()`
      recovers every field from the codec's encoder output). A one-byte change to
      either hand-rolled side now fails a test; the hand-rolled code itself is
      still not replaced.

      **Still open, and deliberately not done in this pass:** `SaftyFW`'s
      `link_frame.c` (`link_frame_pack_fw_version()`) and `KilnFW`'s
      `safety_link.c` still hand-roll Frame C independently against
      `LINK_PROTOCOL.md` §6's offset table — this codec is not yet wired
      into either firmware's real send/receive dispatch, the same
      codec-only state most of the other payload codecs in this checklist
      shipped in first (see "Migration" below). Audited again 2026-08-24
      (before this pass) and unaudited since: the two hand-rolled
      implementations were still in agreement as of that date, so this is
      not a known live bug, but LINK_PROTOCOL.md's own words on this frame
      still apply — migrating both sides is "not safe to do piecemeal from
      one side of the link alone" and needs a dedicated coordinated commit,
      which is out of scope for adding the shared codec itself.

## Related

- [`docs/LINK_PROTOCOL.md`](docs/LINK_PROTOCOL.md) — the wire, both ends.
- [`docs/UPDATE_PROTOCOL.md`](docs/UPDATE_PROTOCOL.md) — firmware updates for
  both processors: interlocks, authentication, ESP OTA partitioning, and the
  frames that carry an image to the Pico over the isolated link. The update
  frame codecs belong in `kilnlink` for the same reason the rest do — one
  implementation, shared test vectors.
- [`docs/BENCHPROTO.md`](docs/BENCHPROTO.md) — the separate `benchproto`
  protocol family's spec: framing, CRC, reliability, and task-registration,
  hardware-agnostic. First (and, since SimFW's 2026-08-28 removal, only
  historical) consumer was SimFW; shares no code with
  `kilnlink` (see that document's section 1 for why).

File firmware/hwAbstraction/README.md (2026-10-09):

# firmware/hwAbstraction

One hardware-abstraction tree shared by KilnFW (ESP32-S3) and SaftyFW
(RP2040). Full history and phase-by-phase record: `docs/HW_ABSTRACTION.md`.

```
hwAbstraction/
  interface/   portable headers only (backend-independent): hal_status.h
               hal_spi.h hal_i2c.h hal_uart.h hal_gpio.h hal_adc.h hal_kv.h
               hal_flash.h hal_scratch.h hal_time.h hal_wdt.h hal_pwm.h
               hal_sysinfo.h. No vendor types. C11 (stdalign.h,
               _Static_assert). Opaque handles, link-time backend, no vtables.
  common/      vendor-neutral shared code (hal_status.c).
  esp/         ESP-IDF backends, plus the SPI/I2C/UART owners and
               uart_protocol relocated in from App/drivers/owners/:
                 esp/spi/  esp_spi_owner.{c,h}, owner_slot_pool.{c,h}, hal_spi_esp.c, hal_spi_esp_owner.h
                 esp/i2c/  i2c_owner.{c,h}, hal_i2c_esp.c, hal_i2c_esp_owner.h
                 esp/uart/ uart_owner.{c,h} (embeds a hal_uart_t), uart_protocol.{c,h}, hal_uart_esp.c
                 esp/gpio/, esp/kv/, esp/time/, esp/wdt/, esp/pwm/, esp/sysinfo/, esp/common/
               esp/CMakeLists.txt is comment-only, not a real ESP-IDF
               component (a bare "esp" component name collides in IDF's flat
               namespace) -- the real component is the thin wrapper at
               idf/hwabstraction_esp/ below, which lists these same sources
               with a "../../esp/" prefix.
  idf/         ESP-IDF component-registration wrappers.
                 idf/hwabstraction_esp/  the real idf_component_register for
                                         esp/ above, named "hwabstraction_esp"
                                         (symmetric with SaftyFW's
                                         "hwabstraction_pico" library target).
  pico/        pico-sdk backends, plus the SPI/UART owners relocated in from
               SaftyFW/src/:
                 pico/spi/    spi_owner.{c,h}, hal_spi_pico.c
                 pico/uart/   uart_owner.c, uart_owner_tx_policy.{c,h},
                              hal_uart_pico_internal.h (renamed from uart_owner.h)
                 pico/gpio/, pico/adc/, pico/flash/, pico/scratch/, pico/wdt/, pico/time/
  host/        fake backends for MSVC host tests: fake_spi/fake_i2c/fake_uart/
               fake_gpio/fake_adc/fake_kv/fake_time/fake_flash/fake_scratch/
               fake_wdt/fake_pwm/fake_sysinfo (12 total, ~785+ assertions,
               each with a proven negative test). Linked into both
               build_host_tests.ps1 scripts per firmware.
  test/        compile_headers.ps1 (MSVC syntax/ABI check for interface/),
               compile_esp_backends.ps1, compile_pico_backends.ps1,
               test_host_fakes.ps1.
```

Status: all planned interfaces have both a real backend (ESP and/or Pico, as
applicable) and a host fake; every named production consumer has been
migrated (see the plan doc's Phase 3 status list for the item-by-item
record). `firmware/UnitTestFw` stays untouched (owner decision) and is not
part of this tree. `firmware/SaftyFW`'s bootloader stays on raw pico-sdk
calls (separate binary, ~64K budget, no FreeRTOS) and is not migrated.

## Conventions (durable — read before adding a backend or a client)

- **No vtables, no function pointers.** Backend is chosen at link time; one
  backend per build.
- **Opaque handles are fixed-size aligned storage, not pointers.** An opaque
  pointer would force heap allocation per device, and several drivers embed
  a handle *by value* (SX1509, FT6336U, NS2009, MAX31856). Shape:
  `typedef struct { alignas(8) uint8_t storage[N]; } hal_xxx_t;` with a
  `_Static_assert(sizeof(struct impl) <= sizeof(storage), ...)` in the
  backend `.c` so growth is a build error, never a memory bug. Use the
  `_Alignas(8)` keyword form, not `<stdalign.h>`'s `alignas` macro — the
  keyword compiles under plain `/std:c11` on every `cl` invocation in this
  tree; the macro form does not without it, and not every invocation passes
  `/std:`.
- **hal_status_t** carries four values beyond the obvious baseline because
  real callers branch on them: `WEDGED` (sticky, distinct from `NOT_READY`
  — recoverable by re-init vs not), `VERIFY_FAILED` (register read-back
  mismatch; callers retry, unlike plain `IO`), `INVALID_SIZE`, `NOT_FOUND`
  (probe loops continue-on-this; folding into `IO` would abort a scan).
  `hal_status_to_name()` returns a **string** — `gpio_probe` forwards it to
  PcTools the same way it forwarded `esp_err_to_name()`, and PcTools matches
  on the text, never a numeric code.
- **hal_kv (NVS) durability contract:** a `set` MAY already be durable
  before `commit`; `commit` guarantees everything before it. Real
  `nvs_set_*` writes to flash immediately, so "nothing durable until commit"
  is the wrong mental model — `fake_kv_simulate_power_loss()` keeps pending
  writes by default; `fake_kv_set_lossy_uncommitted()` opts into discarding
  them, for a test that wants the other side of the contract.
- **NVS keys have a real 15-character limit** (`NVS_KEY_NAME_MAX_SIZE` is
  16 including the NUL terminator). A 16-char key fails silently on real
  hardware (`ESP_ERR_NVS_KEY_TOO_LONG`, and the pre-HAL caller in this tree
  didn't log it) while the old host stub had no key-length check at all and
  passed. `zones_config_store.c`'s `NVS_KEY_ZONE_NORMALS` was exactly this
  bug (`"zone_normals_cfg"`, 16 chars) — every `zone_normals_save()` had
  silently no-opped on every board ever run. Fixed by renaming to
  `"zone_norm_cfg"` (13 chars); a `NVS_KEY_LEN_CHECK` `_Static_assert` macro
  in the same file now catches any future `NVS_KEY_*` literal over 15 chars
  at compile time. `fake_kv.h`'s `FAKE_KV_MAX_KEY_LEN` (16) is deliberately
  left equal to the real limit — raising it would have hidden this class of
  bug, and it is what caught this one.
- **hal_kv is ESP-only.** SaftyFW's `config_store` is not a KV store — it is
  a fixed 512-byte record, seq-numbered, CRC'd, 8-slot round-robin log in one
  4K sector, gated by a hard safety interlock (write refused while the relay
  is ARMED) and format-versioned with a REFUSE-not-reinterpret policy on a
  too-new record. Forcing it through hal_kv would strip the ARMED gate to a
  caller-side check or bloat the interface with slot/seq/ARMED concepts one
  platform needs. It sits on **hal_flash** instead
  (`config_store_flash.c`), keeping the ARMED gate, the seq/CRC log and the
  REFUSE policy intact at that layer. A `hal_kv_pico.c` draft that tried to
  shoehorn config_store onto `hal_kv.h` was rejected on review for exactly
  this reason.
- **hal_flash program semantics:** programming clears bits only
  (`existing & new` per byte) and programming a non-erased byte is
  *permitted*, not refused — matching real NOR flash, where a missing erase
  is a detectable bit pattern, not an error. `hal_flash_safe_execute()`
  wraps the real RP2040 multicore-XIP lockout (`flash_safe_execute()`); it
  is first-class, not an afterthought, because the hazard is real.
- **hal_uart has two send primitives on purpose:**
  `hal_uart_send()` (non-blocking, whole-buffer-or-BUSY) and
  `hal_uart_send_blocking()` (returns only once the last byte is **on the
  wire**). `uart_protocol.c`'s ACK timer starts right after the blocking
  send returns, so a fire-and-forget send would start the timer before the
  last byte left the FIFO. The Pico backend's `send_blocking` drains the
  software TX ring rather than checking true wire completion
  (`UARTFR.BUSY`, not `TXFE` — `TXFE` clears while the last byte is still
  shifting out) because no Pico consumer originates an ACK-timed send today;
  if one ever does, that is the primitive to add, not to assume.
- **One `hal_uart_t` handle per port.** `hal_uart_attach()` (a transitional
  shim letting `uart_protocol_t` borrow the driver's already-installed
  handle) is gone — `uart_owner_t` embeds the real `hal_uart_t` directly and
  hands out a pointer to it.
- **A driver sharing a port with an existing owner *adopts* the owner's bus
  handle** (`hal_spi_bus_adopt()` / the `hal_i2c_esp_owner.h` /
  `hal_spi_esp_owner.h` bridge headers) — it never calls
  `hal_spi_bus_init()`/`hal_i2c_bus_init()` itself. This is how the display
  and thermocouple bus share one physical SPI host without standing up a
  second competing owner task. The `ALREADY_INIT` re-init recovery path in
  both ESP backends was deleted once adopt existed to replace it.
- **`hal_gpio_init_out()` is latch-then-direction, always.** On ESP-IDF,
  `gpio_set_level()` doesn't touch the direction register and
  `gpio_set_direction()` doesn't touch the level register, so
  level-then-config is glitch-free; several call sites in this tree used to
  do it the other way round (a brief asserted-CS window at boot) and were
  fixed by migrating onto this call. On Pico, the same order applies for the
  same reason. This is a **deliberate, noted behavior change**, not a
  no-op refactor, wherever it fixed a pre-existing wrong-order site.
- **hal_scratch (RP2040 watchdog-scratch registry)** is a *runtime* advisory
  claim table keyed on `(slot, tag)`, not a compile-time one — there is no
  `HAL_SCRATCH_CLAIM()` macro. Slot 4 is hard-refused for claim/write/clear
  (pico-sdk's own `watchdog_enable` reserves it); slot 5 has two legitimate
  writers distinguished by tag, cross-documented in code.
  `vApplicationStackOverflowHook()` writes scratch[5] raw, bypassing the
  registry, because no function call is safe to make from that hook — its
  claim is still *registered*, just not routed through the typed accessors.
- **Two raw GPIO IRQ owners stay raw, permanently:** Pico `thermo_task.c`
  (DRDY, a shared per-core dispatcher — a second registrant would clobber
  the first) and ESP `uart_bridge_io.c` (SX1509 ~INT, per-pin ISR). Adding
  `hal_gpio_irq_attach()` is gated on a *second* consumer ever needing one;
  none exists today.
- **hal_adc is Pico-only, deliberately.** No ESP consumer exists in this
  tree, and ESP-IDF's `adc_oneshot`/`adc_cali` model (a unit handle,
  per-channel atten/bitwidth config, a separate calibration handle) doesn't
  fit this interface's Pico-shaped, handle-less, raw-sample-only signature
  without widening it. A speculative `hal_adc_esp.c` was written and deleted
  for this reason — if an ESP consumer is ever proposed, re-derive the
  interface from ESP-IDF's real shape rather than reusing this one.
- **Permanent holdouts, named individually, none of them TODOs:** `main.c`
  (SaftyFW's GPIO6-low boot step 1, the TIMER_DBGPAUSE register, the
  watchdog-caused-reboot checks — none expressible through `hal_wdt.h`/
  `hal_scratch.h` without widening either past what any real consumer
  needs), `console_uart.c` (Pico, write-only diagnostic, no IRQ, boot-banner
  dependency-free by design), `thermo_task.c` and `uart_bridge_io.c` (the
  two raw GPIO IRQ owners above), `main_boot_early.c` (ESP SPI/I2C bus
  bring-up — the HAL doesn't own bus lifecycle, only transfers),
  `wifi_prov`/`lvgl_port` family (own real periodic `esp_timer_create`
  timer objects / are out-of-scope Wi-Fi-httpd-LVGL portability, not a
  get-time-only swap), `esp_ota_ops.h`/OTA partition writes (out of scope —
  a write seam, not a read seam), SaftyFW's bootloader (separate binary,
  shares only `flash_layout.h`), `firmware/UnitTestFw` (owner decision, do
  not re-propose folding it in).
- **`check_hal_include_boundary.ps1` allowlist policy:** every entry is a
  full repo-relative path (never a directory prefix — SaftyFW has no
  `espInterfaces/`-style subdirectory, so a prefix rule would be asymmetric)
  with `@{ RelPath; Header; Reason; ExpiresAtPhase }`. An entry with no real
  `// TEMPORARY` marker in the code carries no `ExpiresAtPhase` — it is a
  permanent, reviewed holdout, not a deferred migration.

## Known coupling

`firmware/SaftyFW/CMakeLists.txt`'s `hwabstraction_pico` target privately
includes SaftyFW's own project root (for `FreeRTOSConfig.h`). Earlier drafts
of three Pico backend files also reached into `SaftyFW/src/` for
`board_pins.h`; that was removed (pin values now arrive as init-time
parameters from SaftyFW's own callers), so the remaining coupling is just
`FreeRTOSConfig.h` — `hwabstraction_pico` is still not buildable as a fully
standalone library outside a SaftyFW-shaped project, but the board-pins
dependency that used to widen this is gone.

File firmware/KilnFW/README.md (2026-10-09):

# KilnCtrl firmware

ESP32-S3 firmware (ESP-IDF) for the **kilnCtl main board**: three MAX31856
thermocouple channels, an SX1509 I/O expander driving four relays and seven
digital I/Os, a 480x320 ILI9488 TFT, and an isolated link (ADuM1201 digital
isolator) to an RP2040 safety processor — all remotely controllable from a PC over a hardened,
reliable UART protocol, plus a Python GUI/MCP server on the PC side to drive
them.

The controller is an ESP32-S3-DevKitC (U4) plugged into the main board.
`docs/HARDWARE.md` is the authority on what is wired to what; it was traced
from `hardware/mainBoard/kiln.kicad_sch` and the two thermocouple daughterboards.

This firmware started as the unit-test fixture's and was retargeted at this
board. The fixture's devices (MCP4728 DAC, AD9833, SSD1306, PCF8575) are gone;
their wire `task_id`s are reused, which is why the protocol version is now
**2**.

## Quick start

```powershell
# ESP-IDF v6.0.2 environment (this machine's export.ps1 is broken; use this)
& 'C:\Espressif\tools\Microsoft.v6.0.2.PowerShell_profile.ps1'

idf.py -C firmware/KilnFW set-target esp32s3
idf.py -C firmware/KilnFW build

# Flash over JTAG with OpenOCD, then monitor
idf.py -C firmware/KilnFW monitor

# PC control GUI -- PcTools serves both processors and lives outside this firmware
uv run --project tools/PcTools kilnctrl-gui
```

Every command above runs **from the repository root**, which is where the editor
and the shell are opened. That is why they carry a path argument: this firmware
is `firmware/KilnFW/`, not the working directory. If you would rather not type
`-C`, `cd firmware/KilnFW` first and drop it — but do not assume a bare
`idf.py build` picks the right project. From the root it fails outright; from the
wrong firmware directory it quietly builds the other one.

In VS Code, open **`kilnCtl.code-workspace`** rather than the folder. The ESP-IDF
extension treats a workspace folder as a single project and needs a
`CMakeLists.txt` in it, which the repository root does not have.

Hardware configuration (every pin, bus, clock and timeout) lives under
`idf.py -C firmware/KilnFW menuconfig` → **KilnCtrl Hardware Configuration**; `App/drivers/hw/settings.h`
translates those into the plain names the drivers use.

### Building against the simulated plant

For developing the control stack without a kiln (or without a thermocouple
daughterboard), `idf.py -C firmware/KilnFW menuconfig` → **KilnCtrl Hardware Configuration** →
**Simulated plant (development only)** → **KILNCTL_SIM_PLANT** (default off)
compiles the host tests' thermal model into the firmware. The profile
executor, autotune engine, and dashboard then read simulated temperatures
instead of the MAX31856 channels, and faults can be injected on the running
board:

```powershell
# Inject: fault = none|element_dead|relay_welded|tc_detached|tc_frozen|tc_open
curl -X POST -d "zone=0&fault=element_dead" http://<board-ip>/api/sim

# Report each zone's true element temperature, reported reading, relay state, fault
curl http://<board-ip>/api/sim
```

**Never flash a sim build to a board wired to elements.** It reports
fabricated temperatures — the UI will show a healthy firing with nothing
plugged in — and relay writes still go out to a real expander if one is
attached. As of 2026-08-12 this build compiles but has not been flashed or
run on hardware. See [`docs/PID_CONTROL.md`](docs/PID_CONTROL.md) and
[`docs/GUARD_TEST_MATRIX.md`](docs/GUARD_TEST_MATRIX.md) for the details.

## Documentation

| Doc | Covers |
|---|---|
| [`docs/HARDWARE.md`](docs/HARDWARE.md) | The board: every ESP32-S3 pin, the SPI and I2C buses, the expander's 16 pins, both daughterboard connectors, the isolation barrier, and the display connector's unresolved pinout |
| [`docs/UART_PROTOCOL.md`](docs/UART_PROTOCOL.md) | The wire protocol (version 2): framing, CRC, reliability/retry/dedup, task registration, and every command payload |
| [`docs/MAX31856.md`](docs/MAX31856.md) | Thermocouple driver: wiring, registers and conversions, API, THERMO subcommands |
| [`docs/SX1509.md`](docs/SX1509.md) | Expander and `kiln_io` board layer: pin map, relay/K numbering, boot order, API, IO subcommands |
| [`docs/DISPLAY_ST7796_WIRING.md`](docs/DISPLAY_ST7796_WIRING.md) | Bench wiring sheet for the MSP4031/ST7796 panel: the J2 harness pin by pin, the two crossovers, the backlight and touch-reset flying wires, and the R4/R6 removal the touch bus requires |
| [`docs/ILI9488.md`](docs/ILI9488.md) | Display driver: the D/C-vs-reset ambiguity, RGB666 over SPI, API, DISPLAY subcommands |
| [`docs/SAFETY_LINK.md`](docs/SAFETY_LINK.md) | The isolated link to the RP2040, the contract its firmware must implement, and the fault line |
| [`docs/SAFETY_MODEL.md`](docs/SAFETY_MODEL.md) | The safety-wins policy: what actually blocks a relay from energizing today, and what still doesn't |
| [`docs/PROJECT_STATUS.md`](docs/PROJECT_STATUS.md) | What's done and verified vs. outstanding, across firmware and PC tooling |
| [`../../tools/PcTools/README.md`](../../tools/PcTools/README.md) | The PC-side Python package: GUI, MCP server, session logging, layout |

## Firmware layout

- `App/main.c` — `app_main`, kept to single-line "start" calls; all task/init
  choreography lives in each driver's own file. Bring-up order is I2C bus →
  SX1509 + `kiln_io` (relays come up **off**) → i2c scan → shared SPI bus →
  MAX31856 channels → ILI9488 → safety link → log bridge → device bridges.
  Only the UART owner and protocol stack abort boot on failure; everything
  else is logged and stepped over.
- `App/drivers/` — `MAX31856`, `SX1509` + `kiln_io`, `ILI9488`, `safety_link`
  device drivers; `espInterfaces/` holds `i2c_owner`, `esp_spi_owner`,
  `uart_owner` (per-bus request-queue owners) and `uart_protocol` (the
  reliable addressed-message layer); `uart_bridge` (one task per wire
  `task_id`); `uart_log_bridge` (forwards every `ESP_LOGx` to the PC);
  `uart_task_ids.h` (the frozen wire contract); `Kconfig` / `settings.h`
  (hardware configuration); `gen_build_info.cmake` (firmware version info,
  regenerated on every build).
- `App/monitor_task.c` — heartbeat. This board has no MCU-driven LED, so by
  default it reports over the log link instead of blinking.

## Two things that bite

- **The shared SPI bus is initialized in `app_main`, not by a driver.** Only
  the first `spi_bus_initialize()` on a host takes effect, and the two drivers
  on that bus want incompatible configurations — `MAX31856_bus_init` asks for
  DMA-disabled with `max_transfer_sz` 17, which would cap the display's
  transfers at 64 bytes. `app_main` brings the bus up once with the display's
  requirements (DMA, 1440-byte transfers); both drivers then find the host
  already up, which each handles.
- **Relay pins high = relays energized**, and the expander's data latch powers
  up at 1. `kiln_io_init` loads all four relay bits low *before* it turns
  those pins into outputs, which is the only ordering that does not click
  every element on for the duration of one I2C transfer at each boot.

## PC tools layout

See [`../../tools/PcTools/README.md`](../../tools/PcTools/README.md) for the full breakdown.

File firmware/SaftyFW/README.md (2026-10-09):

# SaftyFW — kiln safety processor firmware

> **Status:** early implementation, first real-hardware boot succeeded, isolated link now proven end to end · **Last reviewed:** 2026-08-23
> **Keep this file current.** It is the entry point; if the document set or the
> headline facts change, update it in the same commit.

FreeRTOS firmware for the **Raspberry Pi Pico (RP2040)**, designator **A1** on
the kilnCtl main board, running in the isolated `GND_Safty` domain.

**2026-08-18: first flash to a real Pico.** Immediately double-faulted at
boot (`~DRDY` GPIO IRQ armed pre-`vTaskStartScheduler()` called FreeRTOS
ISR-safe APIs before the SMP port's cross-core scheduler state existed --
diagnosed via GDB against OpenOCD's gdbserver, fixed in
`src/tasks/thermo_task.c` by arming the IRQ from inside the task body
instead of from `main()`). After the fix, confirmed via GDB that the idle
task runs normally (thread mode, no exception). No CT transformers or
thermocouple ICs attached yet, so `current_task`/`thermo_task`'s real sensor
paths are still unverified against real hardware -- only scheduler bring-up
and the boot sequence itself are hardware-confirmed so far.

The pico-sdk + FreeRTOS-Kernel (SMP) CMake project, the boot sequence, the
task/priority/core-affinity shells and the isolation CI grep check exist under
`src/` and compile clean under the real arm-none-eabi-gcc/pico-sdk toolchain —
see `TODO.md` for what's built vs. still pending. This directory also
still holds the design documents below, written before implementation so the
thresholds, the wire protocol and the failure analysis could be argued about
while they were still cheap to change.

## What it does

The main controller (ESP32-S3, [`../KilnFW`](../KilnFW)) runs the kiln — PID,
profiles, ramps, web UI, its own seven-guard thermal-protection suite. It is
sophisticated, network-connected, and is where bugs live.

**This processor exists on the assumption that the main controller is wrong.**
It watches, independently:

- a thermocouple — its **own** on J7, or one **borrowed** from the main board,
  or both cross-checking each other,
- **three current-sense channels** fed by external current transformers,
- an **E-stop** input,
- the main controller's **setpoints, measured temperatures and relay
  commands**, received over an isolated link,

and when something has gone badly wrong it **de-energizes K4**, which opens an
upstream mechanical line contactor and removes power from the elements — then
**checks that the current actually stopped**, and escalates loudly if it did not.

It does not control the kiln. It does not improve the firing. It notices, and
it cuts power.

Thirteen guards, of which two only ever warn and three escalate from warning to
trip.
There is deliberately **no over-current guard** — the current channels detect
*load active* and estimate power; fuses and breakers own over-current. The full
set, with thresholds and the argument for each, is in [`docs/SAFETY_MODEL.md`](docs/SAFETY_MODEL.md) §4.

## Three design commitments

**It must not cry wolf.** A safety system that trips spuriously gets bypassed —
reliably, by a reasonable person, eleven hours into a twelve-hour firing, with a
jumper. Every trip must clear two independent bars: a magnitude correct
operation cannot reach, *and* a duration a transient cannot sustain. Most
findings are warnings, not trips. See [`docs/SAFETY_MODEL.md`](docs/SAFETY_MODEL.md) §2.

**A frozen main processor must never hang it.** Nothing on the Pico ever waits
for the ESP: no ACKs, no retries, no blocking transmits. The safety core does
not include the link header; the link task cannot touch the relay; and the two
run on different RP2040 cores. The Pico still transmits — it must, so the main
board can prove it is alive — but it transmits the way a beacon does, not the
way a conversation does. See [`../CommonFW/docs/LINK_PROTOCOL.md`](../CommonFW/docs/LINK_PROTOCOL.md) §2.

**And the main board will not heat without it.** The ESP requests the safety
processor's build identity at boot, receives temperature and current telemetry
every 500 ms, and refuses every heater-on event if that stream stops for more
than 1.5 s — aborting a running firing after 30 s. An unpopulated, unprogrammed
or crashed safety processor means a kiln that will not fire
([`../CommonFW/docs/LINK_PROTOCOL.md`](../CommonFW/docs/LINK_PROTOCOL.md) §8).

## Documents

| Doc | Covers |
|---|---|
| [`docs/HARDWARE.md`](docs/HARDWARE.md) | The traced board: Pico pin map, K4 and the contactor interlock, E-stop and `mainFault` polarity, ADC reference, the back-fed 3V3 rail — **and a correction to `KilnFW`'s isolated-link direction** |
| [`docs/SAFETY_MODEL.md`](docs/SAFETY_MODEL.md) | The nuisance-trip doctrine, the thermocouple-placement modes, all twelve guards with thresholds and rationale, trip semantics, and an honest list of what this does **not** protect against |
| [`../../tools/PcTools/TODO.md`](../../tools/PcTools/TODO.md) | The GUI/MCP server for **both** processors: the move out of `firmware/KilnFW/`, the three transports, and the capabilities that make it usable headlessly |
| [`../CommonFW/README.md`](../CommonFW/README.md) | **The shared link code** — what is shared, what is not, and the rules that let one source build under ESP-IDF, pico-sdk and MSVC |
| [`../CommonFW/docs/LINK_PROTOCOL.md`](../CommonFW/docs/LINK_PROTOCOL.md) | The wire, both ends: framing, the unacknowledged broadcast frame, the ESP→Pico context format, the telemetry frames, **what the web GUI should show**, and the `KilnFW` changes required |
| [`docs/CURRENT_SENSE.md`](docs/CURRENT_SENSE.md) | The analog front end (precision rectifier + 1 s peak hold), why there is no RMS sampler, calibration, and the commissioning check |
| [`docs/THERMOCOUPLE.md`](docs/THERMOCOUPLE.md) | The MAX31856 here vs on the main board, **why type K may be the wrong choice above ~1150 °C**, register configuration, the accuracy budget, and which failure modes read *low* |
| [`docs/ARCHITECTURE.md`](docs/ARCHITECTURE.md) | Toolchain, one-task-per-interface layering, priorities and core affinity, boot order, **RP2040 flash/watchdog/ADC gotchas**, state machine and trip codes |
| [`docs/CONFIG_REFERENCE.md`](docs/CONFIG_REFERENCE.md) | Every tunable in one table with defaults, and whether getting it wrong is dangerous, a nuisance, or cosmetic |
| [`docs/GUARD_TEST_MATRIX.md`](docs/GUARD_TEST_MATRIX.md) | How each guard is provoked on host and hardware — **nuisance-rejection tests first** |
| [`docs/BOOTLOADER.md`](docs/BOOTLOADER.md) | **The RP2040 has no UART bootloader in mask ROM**, so field updates need one written: flash layout, metadata, recovery mode, and the rollback bar an image has to clear |
| [`../CommonFW/docs/UPDATE_PROTOCOL.md`](../CommonFW/docs/UPDATE_PROTOCOL.md) | Updating **both** processors: the interlocks, the one-password authentication, ESP OTA partitioning, and the frames that carry an image over the isolated link |
| [`TODO.md`](TODO.md) | Sequenced build plan, phases 0–10, including the `KilnFW`-side blockers |

## Wiring the E-stop

**What it is for.** The E-stop must remove power from the elements *by itself*,
with no software in the loop. The safety processor's job is not to perform the
stop — it is to **know that the stop happened**, report it, and take a second,
independent swing at it in case the wiring is wrong.

**Use a double-pole switch, normally closed on both poles.**

| Pole | Wire it to | What it does |
|---|---|---|
| 1 | **In series with the large safety relay's coil circuit** — the external line contactor coil, the same circuit K4's contact (J10 pins 1 + 2) sits in | Opening the switch breaks the coil circuit and the contactor drops out by physics. **This is the interlock.** No logic, no firmware, no processor involved. |
| 2 | **J1** (2-pin), as a normally-closed contact to `GND_Safty` | Tells the safety processor that power was cut. **This is telemetry, not the interlock.** |

Both poles are normally closed: pressing the button opens both at once.

```
                         E-stop (double pole, NC)
                        ┌──────────┬──────────┐
  contactor coil ───────┤ pole 1   │  pole 2  ├─── J1 ── GPIO9 (1k pull-up)
        │               └──────────┴──────────┘         │
        └── K4 contact (J10 1+2) ──────────────┘        └── GND_Safty
```

Pole 2's polarity is not optional. GPIO9 has a 1 k pull-up, so a
**normally-closed contact to ground** is the only fail-safe sense: a pressed
button, a cut cable and a pulled connector all read HIGH, and all read as
*stop*. Do not invert this in firmware — that turns the one honestly fail-safe
signal on the board into a fail-danger one (`docs/HARDWARE.md` §5).

**What the firmware does in response.** `discrete_task` debounces GPIO9 for
50 ms, then guard **S7** trips immediately — no further conditions, the fastest
guard in the set. On that trip `safety_core` commands `relay_owner` to
de-energize K4 and latch `TRIPPED`, so **the firmware also drops the relay**
rather than merely reporting. On correctly wired hardware pole 1 has already
opened the coil circuit and this command changes nothing; it exists for the case
where the hardware is wrong. The command is retried every 100 ms tick until it
actually lands (a full command queue must never be a silent one-shot), the trip
latch makes it idempotent under a button held for hours, and none of it needs
the link to the main controller — an E-stop is exactly when that link may also
be gone. `firmware/SaftyFW/test/test_estop_deenergizes_relay.c` pins all of it.

**Polarity is configurable — but one setting is blind.** Param `0x0212`
`estop_active_level` (safety commissioning config, set from the commissioning
page like any other): **`0` = asserted when GPIO9 is HIGH — the default**, the
bench's current wiring, and the only setting under which a **broken E-stop
line is itself a stop** (the 1 k pull-up floats a cut line high, so a pressed
button, a cut cable and a pulled connector all read identically). `1` =
asserted when GPIO9 is LOW, for an installation wired the other way round —
**this setting cannot detect a broken line**, because the pull-up's high is
its "all clear". That is a wiring-time decision, not a firmware one: a
pull-down at the pin would be needed to move which failure is visible. Any
unrecognised stored value falls back to `0`, deliberately. Full table in
[`docs/HARDWARE.md`](docs/HARDWARE.md) §5.2.

**What is covered, and what is not.** Pole 1 alone covers a dead, crashed or
unprogrammed safety processor. The firmware command alone covers a
single-pole switch, a broken pole-1 contact, or coil power arriving from
somewhere it should not. Neither covers a **welded line contactor** — nothing
on this board can (§3 of `docs/HARDWARE.md`); guard S3 will report it and the
current will keep flowing. Nor does anything cover pole 2 being wired but pole
1 not: the firmware would trip and command K4 open, but a welded K4 contact
would then be the only thing between you and a live element, which is why the
series contact — not the firmware — is the interlock.

## Bench verification procedure

Run this **once**, after wiring, before the first real firing, and again
after any rewiring of the E-stop circuit. **No heat is needed or wanted** —
the board can sit cold on the bench the whole time. It tests each pole
independently, because they are independent circuits and either one can be
wrong while the other reads perfectly healthy.

**This fixture, 2026-09-10: pole 1 is permanently unwired, by owner
decision** (`docs/HARDWARE.md` §5.1 "Decision, 2026-09-10"). Step 2's pole 1
check below cannot pass here and is not expected to — skip it, and confirm
`estop_verified` on pole 2 alone: the pole-2 read/debounce/trip/relay-command
chain is what "checked and acted on" means for this fixture, and it is what
`test_estop_deenergizes_relay.c` proves. Do not fabricate a pole 1 result to
satisfy step 2's wording. A future rewiring of this fixture to add pole 1
would restore the full procedure below unchanged.

1. **Power up normally**, E-stop **not** pressed. Confirm the board is idle
   and no guard is tripped (`/safety` or `GET /api/status`).
2. **Press and hold the E-stop.**
   - **Pole 1 (the interlock):** watch or listen to the external line
     contactor. *Correct result:* it audibly/visibly drops out — the same
     click it makes on any normal de-energize. *Failure:* the contactor
     stays engaged, or you cannot tell either way (no visibility into the
     contactor) — stop here and fix the wiring before going further; nothing
     downstream of this pole can be verified by any other step.
   - **Pole 2 (telemetry):** on the same button press, confirm the processor
     saw it — `GET /api/status` (or the diagnostics/safety page) should show
     guard **S7** TRIPPED within about a second. *Correct result:* S7 latches
     TRIPPED. *Failure:* S7 stays clear while the button is held — GPIO9/R10/
     C3/J1 or the button's pole-2 contact is wrong; fix it and re-test before
     proceeding, since an unseen E-stop means the board cannot even report or
     retry the software-side relay drop.
3. **Release the E-stop** and confirm S7 clears (or stays latched if your
   commissioning has it require a manual reset — check whichever behavior
   your commissioning page shows as expected) and the contactor re-engages
   when a heating command is next issued.
4. **Record the result.** If both poles behaved correctly, mark the
   interlock verified: `POST /api/estop/verify` on the main board (or the
   equivalent control on the `/safety` page). This clears the
   `estop_verified` item on `/readiness` — see `estop_verification.h` in
   `KilnFW/App/drivers/safety/` for exactly what is recorded and what later
   invalidates it (changing `estop_active_level`, or a `kiln`/`all`-scope
   factory reset). If either pole failed, **do not confirm** — fix the wiring
   and repeat this whole procedure from step 1.

**Two gaps this procedure — and every layer on this board — leaves open,
regardless of the result above:**

- **A welded line contactor.** If the contactor's contacts are physically
  stuck closed, dropping its coil (pole 1) does nothing, and neither
  firmware nor this procedure has a way to detect it (see "What is covered,
  and what is not" above; guard S3 will eventually report the current that
  keeps flowing, but that is a consequence, not a prevention).
- **`ACTIVE_LOW` polarity plus a cut signal line.** At `estop_active_level =
  1`, the 1 k pull-up's HIGH is "all clear" — a cut cable, a pulled
  connector, or a dead button all read identically to healthy. This is a
  genuine reason to leave the polarity at its **`ACTIVE_HIGH` default**: only
  under that setting does a broken pole-2 line read as a stop rather than as
  silence. If your installation genuinely requires `ACTIVE_LOW`, know that
  this bench procedure's pole-2 check (step 2) is not, on its own, proof
  against a cut line — it will still show S7 tripping on a healthy button
  press, and there is no line-cut fault to inject on a bench pass to
  distinguish the two.

## Three things to know before touching this

**The isolated UART pin map is now a measurement, not a trace.** Measured on
the bench 2026-08-23: ESP TX is **GPIO5** (`DataToSafty`), ESP RX is **GPIO4**
(`DataFromSafty`), and `KILNCTL_SAFETY_TX_IO`/`RX_IO` default to 5/4. `SaftyFW`'s
own pins (`GP4` = TX, `GP5` = RX) never changed and were always right.

This was got wrong twice from the schematic before it was measured — once by
misreading U3's mirrored symbol, and once by trusting R15's position when R15
itself was wired to the wrong net. Do not re-derive it from the symbols; see
([`docs/HARDWARE.md`](docs/HARDWARE.md) §1) for the measurement and both
failures.

**Every relay on this board is a pilot relay, for galvanic isolation only** —
K4 included, and the schematic says so next to it. None carries element current;
they drive external contactors and SSRs. K4 must sit in series with whatever
energizes the load-switching stage, wired so that de-energized K4 = elements
dead. Loss of Pico power, a crash, a watchdog reset, and an unprogrammed Pico
must all land in that state ([`docs/HARDWARE.md`](docs/HARDWARE.md) §3).

**Flash and debug over SWD, and log over the link.** A CMSIS-DAP probe is wired
to the safety processor's SWD header, and `tools/PcTools/src/kilnctrl/debug_probe.py`
(`kiln_call(name="debug_program")`, `target/rp2040.cfg`, 5000 kHz) programs and
debugs it through the same OpenOCD substrate used for ESP flashing — reset,
halt, step and memory read/write are all exposed to an agent this way. The
Pico's console reaches the GUI as `kilnlink` LOG frames relayed by the ESP —
no extra cable ([`../../tools/PcTools/TODO.md`](../../tools/PcTools/TODO.md)).
The safety link itself now runs against the ESP (proven 2026-08-23 once the
baud rate was corrected to 9600 at the time — see `docs/HARDWARE.md` §1 for
that history and `KILNCTL_SAFETY_BAUD_RATE` in `KilnFW/App/drivers/Kconfig`
for the current value, now that the barrier is a digital isolator rather than
an optocoupler pair), but
`ota_update_pico` still cannot be used for first-flash bring-up because its
interlock requires an already-healthy safety link — a chicken-and-egg that SWD
flashing sidesteps.

**Do not connect USB to the Pico while `12v_Safty` is applied.** A1's 3V3 pin is
back-fed from the board's regulator with VSYS and VBUS unconnected; USB would
put the on-module regulator in contention with it. Flash over SWD
([`docs/HARDWARE.md`](docs/HARDWARE.md) §7).

## Related

- [`../CommonFW`](../CommonFW) — the shared link contract and codecs, linked by both firmwares
- [`../../tools/PcTools`](../../tools/PcTools) — one GUI and MCP server for both processors
- [`../KilnFW`](../KilnFW) — ESP32-S3 main controller firmware
- [`../../hardware/mainBoard`](../../hardware/mainBoard) — KiCad project; `output/kiln.pdf` is the
  authoritative schematic. **`kiln.net` is stale — do not trace from it.**
- [`../../hardware/SaftyThermocoupleBoard`](../../hardware/SaftyThermocoupleBoard) — the single-channel
  MAX31856 daughterboard on J7

---

## Completion checklist

High-level only — each document carries its own. Phases refer to [`TODO.md`](TODO.md).

- [x] **Phase 0** safety-UART pin map settled by measurement 2026-08-23 (ESP TX=GPIO5, RX=GPIO4); remaining Phase 0 blockers still open
- [ ] **Phase 1** `CommonFW` extracted and linked by both firmwares
- [x] **Phase 2** skeleton: GPIO6 low first, watchdog, task/core layout —
      done 2026-08-16, build-verified clean under the real toolchain, never
      run on hardware
- [ ] **Phase 3** thermocouple, with `~DRDY` interrupt and silence detection
- [ ] **Phase 4** guards as a pure function, host-tested, nuisance tests first
- [ ] **Phase 5** relay authority, safe state proven four ways, interlock polarity confirmed
- [ ] **Phase 6** current sensing, CT channel mapping confirmed before S3/S4 enabled
- [ ] **Phase 7** link: context, ceiling, clear, borrowed-source guards
- [ ] **Phase 8** telemetry and the ESP web GUI panel
- [ ] **Phase 9** commissioning, guard test matrix worked end to end, gaps recorded
- [ ] `SAFETY_MODEL.md`'s summary table updated with per-row verification state
- [ ] Board-change proposals for the next revision written up, not forgotten

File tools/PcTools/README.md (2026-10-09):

# PcTools / kilnctrl

PC-side counterpart to the kilnCtl main board's hardened UART protocol,
implemented in `App/drivers/espInterfaces/uart_protocol.{c,h}` and addressed by
`App/drivers/uart_task_ids.h`. That header is the wire contract: every task id,
subcommand and payload layout here matches it byte for byte.

What is on the other end (see [`../../firmware/KilnFW/docs/HARDWARE.md`](../../firmware/KilnFW/docs/HARDWARE.md) for
the full trace): an **ESP32-S3-DevKitC** driving three **MAX31856**
thermocouple channels over J6, an **SX1509** I/O expander (four relays, seven
digital I/O, the three `~DRDY` inputs, and the display's D/C and `~RESET`), an
**ILI9488** 480x320 TFT on J2, and an opto-isolated link to an **RP2040**
safety processor.

## Physical connection

The dev board has **two USB-C ports**. This protocol runs on UART0 (115200 8N1,
no flow control) exposed through the **USB-UART bridge** port (CP210x / CH340 /
FTDI), *not* the ESP32-S3's native USB-Serial-JTAG port. Port autodiscovery
scores JTAG-looking ports negatively for exactly this reason.

## Usage

Commands are written to run **from the repository root**. This package lives at
`tools/PcTools/`; it moved out of `KilnFW/pc_tools/` because it serves both
processors, so it is no longer inside either firmware.

```powershell
# Tkinter manual-control GUI
uv run --project tools/PcTools kilnctrl-gui

# MCP server (streamable HTTP on 127.0.0.1:8767/mcp)
uv run --project tools/PcTools kilnctrl-mcp-server
```

Both are also VS Code tasks — **"PcTools: Open GUI"** and
**"PcTools: Run MCP Server"**, defined in `kilnCtl.code-workspace` rather than in
a firmware's `tasks.json`, since neither belongs to one firmware. In practice the
servers are usually already running (status-bar buttons / workspace auto-start);
see **[`../../docs/MCP_SERVERS.md`](../../docs/MCP_SERVERS.md)** for how they are
started and stopped, the six-tool search facade both publish, and
`--transport stdio` for headless/CI use.

The package still imports as `kilnctrl`: that is the *system's* name, not the
main board's, so the directory moved and the package did not.

## Layout

| module | role |
| --- | --- |
| `protocol.py` | SLIP framing, CRC-16/CCITT-FALSE, `Frame`, enums, task ids, every subcommand constant |
| `serial_link.py` | `UartLink` (reader thread, retry/ACK logic), port discovery |
| `link_hub.py` | Lets several `kilnctrl` processes share one physical port |
| `devices.py` | Payload builders + response parsers for all twelve tasks |
| `thermo.py` | `ThermoClient`: owns task 1, MAX31856 queries + the auto-report push |
| `io_expander.py` | `IoClient`: owns task 2, SX1509 queries + the auto-report push |
| `info.py` | `InfoClient`: owns task 3, pin config / FW version, spots boot pushes |
| `display.py` | `DisplayClient`: owns task 4, READ_ID plus the blit stream; Pillow image conversion and a test-pattern generator |
| `device_log.py` | `LogClient`: owns task 5, the firmware's forwarded ESP_LOGx output |
| `safety.py` | `SafetyClient`: owns task 7, the isolated RP2040 link |
| `control.py` | `ControlClient`: owns task 8, zone PID/plant-model read + narrow writes |
| `profiles.py` | `ProfilesClient`: owns task 9, fire profile CRUD + execution control |
| `autotune.py` | `AutotuneClient`: owns task 10, PID autotune status/start/abort/accept |
| `wifi_uart.py` | `WifiUartClient`: owns task 11, Wi-Fi status/scan/provision/forget over UART |
| `probe.py` | `ProbeClient`: owns task 12, raw ESP32 GPIO probe (only on a `CONFIG_KILNCTL_ENABLE_GPIO_PROBE` build, default off) |
| `pin_overlay.py` | Badge coordinates in `assets/pinout.png` + overlay drawing |
| `session_log.py` | Per-session log files, semantic rollover, retention setting |
| `settings.py` | Persisted app settings (`settings.json`): last-used port, log retention |
| `actions.py` | Named-action registry (one entry per GUI button) backing `press_button` |
| `mcp_server.py` | MCP tools over streamable HTTP, plus the generic `press_button`/`list_buttons` pair |
| `gui.py` | Tkinter GUI: `manualCtrl`, `Logs` and `About` menus |
| `logic_capture.py` | Saleae Logic 2 automation-API (gRPC) client: device list, timed digital capture |

The `uart_*` naming inside those modules still refers to the UART protocol
itself, which has not changed; only the package identity did (`uart_control` ->
`kilnctrl`).

## Device pages / tool groups

Each device gets one GUI page, one action group and one MCP tool group, all
three built on the same `devices.py` builders.

### Thermocouples -- task 1 (`manualCtrl -> Thermocouples`)

Per-channel type (B/E/J/K/N/R/S/T plus the two raw voltage modes), averaging,
50/60 Hz filter, one-shot vs automatic conversion, TC and cold-junction
thresholds, cold-junction offset, fault read/clear, and raw register
read/write.

The live temperature readout is fed by the firmware's **auto-report push**
(`SET_AUTO_REPORT`), not by a polling loop: one frame per period carries all
three channels, and the page turns reporting off again when it closes. Faults
are shown as decoded text -- "open circuit (no thermocouple?)" -- never as a
hex byte.

`~DRDY` does **not** reach the ESP32 on this board. It goes to the SX1509, so
conversion-ready is reported by the I/O page, not here.

### I/O & Relays -- task 2 (`manualCtrl -> I/O & Relays`)

**Relay numbering is not K numbering**, and the UI says so on every row:

| control | schematic net | contactor | terminal block |
| --- | --- | --- | --- |
| Relay 1 | `Relay1` | **K3** | J8 |
| Relay 2 | `Relay2` | **K1** | J3 |
| Relay 3 | `Relay3` | **K2** | J4 |
| Relay 4 | `Relay4` | **K5** | J11 |

The firmware exposes the schematic's `Relay1..4` numbering rather than silently
renumbering, so the mapping is spelled out in the GUI rows, in every action
description and in every MCP tool docstring. Also on the page: digital I/O 1-7
with direction and pull-up control and a live level read, a DRDY indicator per
thermocouple channel, and a raw-register section (read/write, dir / pull-up /
open-drain / debounce / interrupt masks, the LED driver, soft and hard reset,
and an I2C scan). Expander state is pushed on a period *and* immediately on
every `~INT` edge, so an input change appears without waiting out the period.

### Display -- task 4 (`manualCtrl -> Display`)

Reset (soft or via the expander's `~RESET`), power, rotation, invert, clear,
fill/draw rect, draw line, text cursor/style/print, and `READ_ID` -- the only
way to tell a wired-up panel from drawing commands vanishing into an
unconnected connector.

**Send an image** is implemented: "Open Image..." loads a PNG/JPEG, scales it
to the panel (letterboxed by default so nothing is silently stretched),
converts to RGB565 and streams it with `BLIT_BEGIN`/`BLIT_DATA`/`BLIT_END`,
with a progress bar. Pillow is a declared dependency for this, imported lazily
so the rest of the package still works without it. **Test Pattern** streams
colour bars plus a grey ramp through the identical path and needs neither an
image file nor Pillow -- the bars make a swapped colour channel obvious and the
ramp catches an RGB565->RGB666 expansion that lost its low bits.

Expect this to be slow: RGB565 fits 63 pixels per protocol frame, so a full
480x320 image is ~2440 frames, on the order of a minute at 115200 baud. The
page says so rather than letting it look like a hang.

### Safety processor -- task 7 (`manualCtrl -> Safety Processor`)

Status of the isolated link, the fault line, E-stop, safety relay K4, heating
enable, the safety thermocouple and the three current-sense channels, plus
request-enable, ping, poll period and a manual fault-line override.

Two things this page is careful about, both easy to get backwards:

* **The isolated fault line is an ESP *output*.** GPIO6 drives U1's LED, which
  pulls the Pico's `mainFault` input low: it is this firmware telling the
  safety processor that the main controller has faulted. There is no hardware
  path for the Pico to signal the ESP at all. The firmware asserts it by itself
  on PC-link loss, a thermocouple fault or a watchdog trip; `SET_FAULT_OUT` is
  a manual override of that.
* **"Link down" is the expected state today.** The RP2040 firmware that would
  answer this protocol does not exist in this repository yet, so `link_up = 0`
  with age "never received" is normal. The page leads with a banner saying so
  and colours that state amber rather than red -- painting a known-absent
  peer as a fault just trains people to ignore the colour that should mean
  something.

`GET_STATUS` never blocks on the far side: the ESP polls on its own schedule
and caches the last good answer, so a dead link is a *successful* query
reporting `link_up = 0`, and a raised `SafetyQueryError` means the **ESP**
didn't answer -- a different fault entirely.

### Zones / PID -- task 8 (`manualCtrl -> Zones / PID (UART)`)

Read-back of every zone's PID gains, plant model and configured limits, plus
narrow writes: `Set PID` (Kp/Ki/Kd) and `Set Model` (K_dc/tau_s/dead_time_s;
an all-zero triple clears the model). Both writes reply ok/fail immediately
rather than silently, so a rejected zone index or out-of-range gain shows up
right away. `/api/zones`' whole-page fields -- zone naming, relay assignment,
heater window timing, cross-zone guard threshold -- are **not** writable here
(that endpoint validates ~20 fields per zone together and doesn't decompose
into a safe per-field wire write); use the web dashboard for those. Manual
relay control is the I/O page's `Set Relay`/`Set Relay Mask`, not duplicated
here.

### Fire Profiles -- task 9 (`manualCtrl -> Fire Profiles (UART)`)

List/create/edit/delete stored profiles (name, zone mask, up to 12 segments of
target_c/ramp_c_per_hr/dwell_min), and drive execution: start, stop, pause,
resume, acknowledge the last run, and a live exec-status readout (state,
segment progress, ramp-lock, per-zone actual/duty/fault). Every mutating
command replies ok/fail (+ error text on `Save`/`Start` failure) rather than
leaving the GUI to find out on the next poll.

### Autotune -- task 10 (`manualCtrl -> Autotune (UART)`)

Status (state/method/zone/elapsed/samples/fitted model/proposed gains/
predicted max ramp), start (step or relay method, with the same
setpoint/duty/relay-d/relay-h/rule fields the HTTP form exposes), abort and
accept. The cross-zone coupling matrix and the trace/history CSV dumps stay
HTTP-only (Open Web Dashboard) -- bulk/table data that doesn't fit one
253-byte frame and has no honest truncated form.

### Danger Zone -- factory reset (`manualCtrl -> Danger Zone (Factory Reset)`)

Scope-selectable factory reset (Wi-Fi only / kiln config only / profiles only
/ all) over UART (`SYSTEM_CMD_FACTORY_RESET`), so it works with no network.
Destructive on real hardware: a confirmation dialog followed by a
type-to-confirm text prompt, no default scope pre-selected. Mirrors
`POST /api/factory_reset` exactly -- same per-partition NVS erase, same
unconditional reboot ~500ms later; no reply frame either way, so the ACK is
the only immediate confirmation and the reboot itself (a fresh unsolicited
`GET_FW_VERSION` push) is the real evidence the erase happened.

### Wi-Fi Settings -- HTTP or UART (`manualCtrl -> Wi-Fi Settings`)

The existing HTTP-based popup gained a **"Use UART (no network needed)"**
checkbox: when checked, Refresh Status / Scan / Connect / mode switch go over
task 11 (`WifiUartClient`) instead of `urllib` HTTP against the host/IP field
-- the point being that Wi-Fi can be provisioned before the board has ever
joined a network, when there's no HTTP path to it yet. AP-identity editing
(`SET_AP_IDENTITY`) stays HTTP-only in this pass. The read-only Firing Status
popup is unchanged.

## Config presets

A named, known-good starting config, so a test run begins from the same board
twice. Presets are **DATA** under `config_presets/*.json`, never compiled into
firmware -- the bench fixture's 80 °C ceilings must not be capable of riding
into a real kiln build.

```
kiln_call(name="list_config_presets")
kiln_call(name="load_config_preset", args={"name": "bench_fixture",
                                            "host": "192.168.1.156",
                                            "safety_host": "192.168.1.156"})
kiln_call(name="factory_default_then_load_preset", args={"name": "bench_fixture"})
```

A preset is applied over three write paths, each verified by an independent
read-back (an ACK is never accepted as proof that a value landed):

| Section | Path | Reached with |
|---|---|---|
| `zones[].pid_*` / model | UART CONTROL task (`control.py`) | always |
| the rest of `zones_cfg_t` | `GET`/`POST /api/zones` (`zones_http_client.py`) | `host=` |
| `"safety"` | `POST /api/safety/commissioning` (`safety_cfg_http_client.py`) | `safety_host=` |
| `ramp_assist_enabled` | `POST /api/ramp_assist` (`ramp_assist_http_client.py`) | `host=` |

`host` and `safety_host` are normally the **same address**: both endpoints are
served by the ESP32, which is the only thing that can talk to the RP2040 at
all. Omit either and that section is reported as reference data, not written.

**`ramp_assist_enabled` is a REQUIRED top-level field on every preset, not
optional.** It pins the kiln-wide "ramp assist" flag (`docs/PID_EXPANSION_
PLAN.md` §7.5) to a known value rather than letting an experiment inherit
whatever the board happens to already have. This is not a style preference:
enabling ramp assist mid-run lets the executor silently stretch a ramp or
shorten a dwell, which invalidates a PID tuning run or A/B controller
comparison's tracking-error numbers outright. Every preset shipped in
`config_presets/` pins it `false`. `run_queue.py`'s HTTP-only apply path pins
it the same way, so a queued campaign can never start a firing without an
explicit answer to "is ramp assist on."

**The `"safety_ct_channel_map_backup"` section is never applied by default.**
`ct_channel_map[0..2]` states which relay each current transformer is
physically clamped around; committing all three makes the safety processor
clear `calibration_missing` and therefore grant heat. On a bench with no CT
fitted there is nothing for that map to be true about, so the assumed identity
map lives in its own section and is written only when a caller knowingly
passes `use_ct_map_backup=True` (a host-test scenario, or a deliberate
exercise of `commissioning_gate.c`'s accept path). The real map comes from the
zone current-sweep on the zones page once CTs exist.

## Config package conversion (`cfg_convert`)

`src/kilnctrl/cfg_convert.py` converts a kiln backup package -- the JSON
document `GET /api/backup/export` produces and `POST /api/backup/import`
accepts (`firmware/KilnFW/App/drivers/http/backup_export.c`/
`backup_import.c`) -- from any `BACKUP_FORMAT_VERSION` to any other, in
either direction, best effort. This is entirely a PC-side tool: the board
itself keeps its firmware migration limited to exactly one step, the version
it was built against minus one (`docs/CONFIG_MIGRATION_CHAIN_PLAN.md`), so a
board more than one release behind cannot read its own on-flash config and
would fall back to firmware defaults on its own. `cfg_convert` closes that
gap off-board: it produces a package already expressed in the shape the
target board's own firmware understands, so a restore never hands a board a
package it cannot read.

```powershell
# Convert a downloaded backup to an older package format (version 2):
python -m kilnctrl.cfg_convert C:\backups\kiln_2026-09-10.json --to-version 2 -o converted.json

# Convert to whatever format the board at this address currently understands,
# read live over HTTP from its own GET /api/backup/export -- no need to know
# the number:
python -m kilnctrl.cfg_convert C:\backups\kiln_2026-09-10.json --to-board 192.168.1.42 -o converted.json
```

Installed as the `kilnctrl-cfg-convert` console script too, once the venv is
active (`kilnctrl-cfg-convert <input> --to-version 2 -o converted.json`).

**Forward conversion** (older document to a newer version) follows the same
additive-field semantics the firmware's own backup exporter/importer already
use: most fields introduced by a later firmware are optional, presence-gated
keys that a document simply may or may not carry, so "converting forward"
mostly means leaving them unset rather than inventing a value for them. The
one genuinely structural change in the format's history is how zone-to-zone
thermal coupling is expressed -- a single `coupling_coeff`/
`coupling_neighbor_zone` pair (versions 1-3) versus a full `coupling_c<N>`
row, one key per neighbor channel (version 4 onward) -- and `cfg_convert`
expands or collapses that representation explicitly.

**Backward conversion is best effort by definition:** a field the target
version's document shape cannot express is dropped, and a coupling row with
more than one real neighbor collapses to whichever single coefficient has
the larger magnitude, discarding the rest. Every conversion prints (and can
write to a `--report` JSON file) a line for every field that did not survive
intact, naming it as `dropped`, `derived`, or `kept` with a short reason --
for example, collapsing a full coupling row into the single-neighbor v3
format reports the discarded neighbor(s) by name, and expanding a
single-neighbor v3 pair into a v4 row reports which channels are *derived*
zeros rather than real measurements. Running the same document A -> B -> A
does not silently "round-trip" -- the report on the second hop shows plainly
that the fields dropped on the way to B were not restored, because they no
longer exist anywhere to restore from.

**`cfg_convert` never fabricates a calibration value.** If the target
version has a calibration field (`normal_current_a` on the ESP zone side;
the Pico/SaftyFW-side analogue is `i_normal_a`, not carried in today's ESP
backup document but guarded the same way) that the source document does not
have, the output simply does not have it either -- it is never defaulted,
derived, or copied from another zone. An uncalibrated CT channel correctly
leaves its guard dormant; a fabricated reading would arm that guard on a
lie, which is worse.

**`cfg_convert` never reads or emits a credential.** It refuses outright
(exits non-zero, writes nothing) if the input document contains a
`kiln_auth` key or any Wi-Fi-credential-shaped key (SSID, password, PSK) at
any depth -- the real export format never contains these, so their presence
means the document should not be trusted, not that they should be quietly
carried through or stripped.

Because this module duplicates firmware's own idea of what a backup document
contains, `firmware/KilnFW/App/test/cfg_convert_field_mirror_drift_check.py`
(wired into `tools/run_all_checks.ps1` via
`check_cfg_convert_field_mirror_drift.ps1`, same as the project's other
`*_mirror_drift_check.py` scripts) extracts the live field vocabulary and
`BACKUP_FORMAT_VERSION`/`BACKUP_FORMAT_VERSION_MIN` constants straight out of
`backup_export.c`/`backup_import.c`/`backup_http_internal.h` and fails the
build the moment `cfg_convert.py`'s own copy disagrees.

Tests: `tools/PcTools/tests/test_cfg_convert.py`, run through pytest. Its
fixtures under `tests/fixtures/cfg_convert/` are **synthesized**, not
captured from a real board -- see that directory's own `README.md` for where
a real capture should live once one exists (the owner's release-step
requirement is to capture one before every version bump).

## Gate fields -- config values that make a feature REACHABLE, not just configured

`src/kilnctrl/gate_fields.py` is the checked-in inventory of **gate fields**:
config values that skip a whole feature/subsystem for one of their values
(`control_mode` gating the fuzzy PID layer is the archetype -- the fuzzy
layer only runs under `control_mode == 3`; `ct_installed` gating the
current-transformer-dependent safety guards S3/S4/S9/S11/S14 is another),
as distinct from fields that merely **tune** a feature that is already
running (`pid_kp` never skips the PID loop, at any value). Two incidents
paid for this list: an analysis pooled 28 `control_mode: 2` captures with
one `control_mode: 3` capture and reported a 37,008-sample conclusion whose
real n was 2178; separately, two campaigns ran for hours believing the
fuzzy layer was active because the readback checked `fuzzy_strength_pct`
(a tuning field) instead of `control_mode` (the gate). The list is not
exhaustive -- see the module docstring for what has and has not been
confirmed by reading the actual gating code.

Two consumers of that inventory:

* **`_check_gate_fields_consistent` in `run_queue.py`** -- runs during
  campaign preflight, before any board is touched (alongside the existing
  B9 arms-differ check): refuses a preset that sets a gated feature's
  tuning field without pinning that feature's gate to a reachable value in
  the same zone. This is the authoring-time fix for the "checked the wrong
  field" incident above. Every applied preset's gate values are also
  snapshotted into the capture's `meta` header line
  (`gate_fields.summarize_preset_gates`), so a capture answers "which
  gated features were reachable during this run" from its own header.
* **`capture_pool_provenance.py`** -- the general, N-file form of the
  pooling incident above: given a list of capture `.jsonl` paths and a gate
  field name, refuses (`assert_pool_gate_consistent`) or reports
  (`check_pool_gate_consistency`) a pool that mixes files where the gate
  was reachable with files where it was not, checked per zone from the
  per-tick `exec.zones[].<field>` telemetry every HTTP capture already
  records. Works for any gate field with per-sample telemetry (today:
  `control_mode`), not only the fuzzy layer -- a new gated feature gets
  this check for free rather than a bespoke pooling script. Complements
  (does not duplicate) `fuzzy_band_probe.py`'s own per-file, per-tick
  `control_mode` filtering for its membership-band math, and
  `bd_reachability_check.py`'s two-arm `bd_*` telemetry comparison:
  ```
  python -m kilnctrl.capture_pool_provenance control_mode capture1.jsonl capture2.jsonl ...
  ```

## Live-bench test harness (pytest)

`tests/bench_fixture_session.py` is the reusable precondition the live tests
were missing: **"the board is sitting on `config_presets/bench_fixture.json`,
and that has been read back and confirmed."** `tests/conftest.py` exposes it
as pytest fixtures, so the next live test that needs a known starting config
(zone PID behavior, autotune, dashboard reporting) takes one argument instead
of re-deriving what the board was configured with.

```
# host-only, the default -- no hardware, nothing skipped silently
python -m pytest tools/PcTools/tests -q

# including the live-bench tests
KILNCTRL_BENCH_HOST=192.168.1.156 python -m pytest tools/PcTools/tests -q -s
```

Without `KILNCTRL_BENCH_HOST` every live test **skips**; there is no mock
standing in for the board.

| Fixture | Scope | What it gives you |
|---|---|---|
| `bench_host_addr` | session | the address, or a skip |
| `bench_session` | session | a `BenchSession` whose zones + safety config were written **and verified** once |
| `bench` | function | the same session plus a `finally` teardown that force-stops the executor and asserts every relay is off |
| `cold_bench` | function | `bench`, plus the guarantee that the bench **started cold** — see below |
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

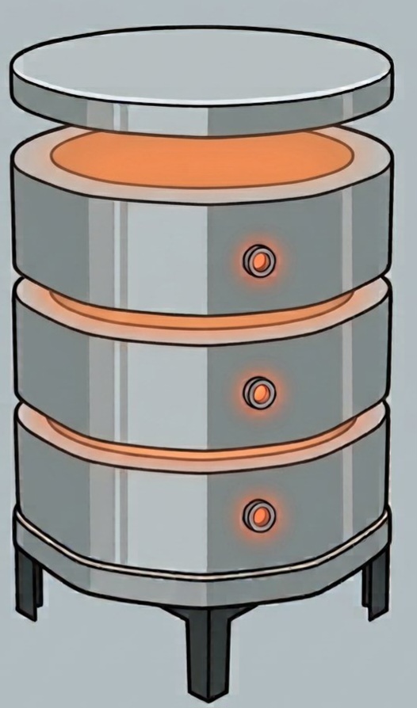
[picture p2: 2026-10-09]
docs/images/zone_graphic_reference_stacked_rings.jpg

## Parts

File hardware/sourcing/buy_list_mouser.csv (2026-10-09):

Mouser Part Number | Quantity
MAXM17572AMC+T | 4
MAX31856MUD+T | 4
ESP32-S3-DevKitC-1U-N8R8 | 1
EE2-12NUH-L | 5
AD8542ARMZ-REEL | 10
UCM1H471MNJ1MS | 4
1935161 | 18
CL32A476KOJNNNE | 8
1935174 | 6
SJ2-35813B-SMT-TR | 3
SS16FP | 13
GRM31CZ72A475KE11L | 10
SC0915 | 1
TCMT1100 | 10
CL32B226KAJNNNE | 5
SX1509BIULTRT | 1
SMAJ24CA | 10
SZNUP2105LT1G | 8
74269244182 | 26
CL31B225KBHNFNE | 31
RCA040210K0FKED | 38
VLMTG1500-GS08 | 6
CRGCQ2512F100R | 10
BSS138P,215 | 10
TSW-120-08-T-S-RA | 1
C0805C105J3RECTU | 10
B10B-XH-AM(LF)(SN) | 3
BZX84C3V3LT1G | 11
GCM155R71H104KE02J | 45
CRCW04020000Z0EDHP | 30
CR2010-J/-000ELF | 15
UMK105BJ103KVHF | 40
GRM1555C1H682GE01D | 10
RCS04021K00FKED | 10
GCM1555C1H4R7BA16J | 13
MCS04020C1200FE000 | 10
CRCW04021M00FKED | 11
CR0402-JW-222GLF | 24
CRCW0402680RFKED | 10
CRCW040233K2FKED | 10
CRCW0402110KFKED | 10
CRCW040241K2FKED | 10
CRCW040221K5FKED | 10
CRCW0402118KFKED | 10
CRCW040225K5FKED | 10
CRCW040271K5FKED | 10
CRCW040210K0FKED | 10
RK73H1ETTP2201F | 10
CR0805-JW-222ELF | 10
CR0402-FX-7151GLF | 10

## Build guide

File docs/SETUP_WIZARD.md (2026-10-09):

# Whole-Kiln Setup Wizard

> **Status: COMPLETE.** All 13 wizard steps and all 11 implementation steps
> below have landed and are exercised by `test_setup_wizard.js` /
> `test_setup_wizard_progress.c` (`check_js_host_tests.ps1`). This file is
> kept as the as-built reference (design rationale, the reuse map, the
> safety rules) now that nothing in it is open -- the `_PLAN` suffix was
> dropped per this repo's standing convention (`feedback_completed_plans_lose_plan_suffix`)
> and every citing file was repointed to `docs/SETUP_WIZARD.md`.
>
> **2026-09-09 pass:** closed the one real gap found against the newly-landed
> firing interlock, `readiness_gate.c`/`.h` (owner decision 2026-09-09:
> `/api/readiness` now actually blocks a firing on `safety_trip`,
> `recovery_mode`, `crash_report`, `estop_verified`, no override). The
> wizard's `computeCompleteness()` was already correct by construction --it
> iterates every item in the raw `/api/readiness` response, not just the keys
> any of the 13 `WIZARD_STEPS` rows declares, so a whole-board item no step
> tracks (`crash_report`, `recovery_mode`, `safety_trip`, `estop_verified`,
> `safety_context`, `cfg_fs`) already blocked "Setup complete" the instant
> `readiness_http.c` reported it `not_done`, since both sides read the SAME
> `readiness_*_status()` predicates readiness_gate.h now also gates on -- no
> second, wizard-owned copy exists to drift from it. That absence of a bug
> was not previously proven by a test, though: no assertion exercised an
> unmapped whole-board item, and the bench board's live `/api/readiness` at
> the time (`crash_report`/`estop_verified` both `not_done`, from an
> unacknowledged panic during a heating run that same day) was exactly the
> shape a wizard-owned copy would have gotten wrong. Added
> `testGateBlocksOnUnmappedFiringGateItem()` to `test_setup_wizard.js`,
> reproducing that exact live shape (all 13 steps done, all step-tracked
> readiness keys `ok`, but `crash_report`/`estop_verified` `not_done`) and
> asserting the gate still refuses and names both. Negative-tested by hand:
> changed `computeCompleteness()`'s `items.forEach` condition to
> `if (false && (it.status === 'not_done' || ...))`, reran
> `test_setup_wizard.js`, got 6 RED (including the new test), reverted the
> line by hand, confirmed `git diff` on `setup_wizard_page.html` empty before
> committing. No production logic changed -- the gap was in test coverage,
> not behavior.
>
> Prior history: implementation steps 1-7 landed 2026-09-08 (progress store,
> `/api/setup/progress`, the `/setup` page shell, and steps 0-6's real
> content: preflight, network/time/units, zone count + thermocouple channel
> assignment, thermocouple types + calibration offsets, zone type (heater vs
> on/off), relay assignment + names + `max_simultaneous_relays`, and zone
> commissioning limits incl. the abs-max-vs-Pico-ceiling refusal); steps
> 8-11 (safety processor, CT setup, autotune) not started as of that pass;
> **this pass** landed steps 8-9 (CT install/topology/mapping review, and CT
> mapping verification under load), 10-11 (PID gains -- autotune-or-hand-
> entered, explicitly either counts as complete -- and the optional coupling
> matrix review), and step 12 (final gate screen, consuming the already-
> landed `computeCompleteness()` rather than reimplementing it). Step 7
> (safety processor commissioning) landed in a separate, concurrent pass
> (commit noted at that step's row below) -- **embedded** inline per owner
> decision, reusing the existing `/api/safety/commissioning` write path and
> its `confirm_commit_landed()` read-back via a newly-extracted shared file,
> `commissioning_shared.js`, rather than a second confirm-and-verify
> implementation. All 13 steps now have real content. **Opened:**
> 2026-09-08.
> Owner request, verbatim: *"like the safety commissioning wizard i want a
> wizard that guides me through the entire setup process of the kiln. ie pid,
> zones, current exc. including the safety processor."*
>
> **One-line goal:** one page, `/setup`, that walks a new owner from a blank
> board to a kiln that `/api/readiness` reports fully ready — reusing every
> existing endpoint, adding no second copy of any validation rule.
>
> **Owner decisions (2026-09-08), settled, build to these:**
> 1. **Embed** the safety-processor commissioning inline in the wizard
>    (embed over link-out, section 10 Q2) — but reuse the existing write path
>    and its `confirm_commit_landed()` read-back
>    (`safety_set_commissioning_fields` / the commissioning commit endpoint)
>    rather than a second implementation of confirm-and-verify. If a future
>    pass finds itself copying that logic, extract and share it instead.
> 2. **Offer, do not force** (section 10 Q6): an unconfigured board gets a
>    prompt/banner pointing at `/setup`; no forced redirect.
> 3. **Hand-entered PID gains complete step 10** — autotune is not mandatory
>    (section 10 Q4). The step's own UI must say so explicitly, so the choice
>    reads as deliberate rather than as a shortcut nobody noticed.

---

## 1. The model: how the safety commissioning wizard works

`firmware/KilnFW/App/drivers/http/safety_commissioning_page.html` (served by
`safety_cfg_http.c`, route `/safety/commissioning`). Extract this pattern; do
not invent a second idiom.

| Aspect | What it does | Where |
|---|---|---|
| Structure | `#guided` div holds `.gscreen0..4`, one visible at a time via `gGoto(n)`; a `.gstepper` renders `GSTEP_NAMES` with `.current`/`.done` classes | page JS `gGoto`, `gRenderStepper` |
| Screen 0 | "Before you start": preflight status line (`link_up`, `commissioned`), write-window banner, `gStart()` which **refuses to advance** if the initial load failed (`gLoadFailed`) | `gRenderPreflight`, `gRenderLoadFailure` |
| Answers | Choices are `.radio-card`s, each with a `.consequence` span spelling out *which guards this answer turns off*. Unavailable choices get `.radio-card.disabled` with the reason in `--bad` | screens 1–2 |
| Validation | Per-screen `gValidateScreenN()` gates `Next`; cross-field contradictions (`checkTcMaxContradiction()`) are re-checked **again at commit**, because the review screen's advisory text was once the only check and could be walked past (fix "F3") | `gCommit()` |
| Review | Screen 3 renders every answer as `.review-row` name/value before anything is written | `gRenderReview` |
| Write | Screen 4 stages all params and issues **one** `POST /api/safety/commissioning` with `commit=1` | `gCommit()` |
| Success is never assumed | A rejected commit is **HTTP 200** with `{"ok":false,"reason":...}`. `res.ok` alone is never trusted; the parsed body's own `ok` is. Server-side `confirm_commit_landed()` re-reads from the Pico; the page then does its **own** second read-back of the fields it changed and fails loudly, naming the field, on mismatch | `gCommit`, `findCriticalChanges` |
| Cannot-complete | ARMED refusal is detected by regex on the reason, then `gStartWriteWindowRetry()` retries every 3 s × 15 with an honest banner — it never renders a countdown of a window it cannot observe (fix "F2") | `gStartWriteWindowRetry` |
| Destructive confirm | `tc_type`/`tc_offset_c` changes require an explicit **named** confirmation before reaching the wire, and refuse mid-run | `findCriticalChanges`, `doSubmit` |
| Busy refusal | `checkFiringOrAutotuneRunning()` polls `/api/profile_exec` + `/api/autotune` and refuses; a *failed* fetch never blocks (Pico's ARMED refusal is the backstop) | same |
| Reload / interruption | **Progress is NOT persisted.** All state is browser-local (`gQ2Choice`, `gPrefilled`); a reload restarts at screen 0 and re-prefills from the board. Acceptable there (4 questions), **not acceptable for a multi-day setup** — see §5 |
| Degrade gracefully | Every auxiliary fetch (`/api/zones`, `/api/zones/ct_channel_map`) `.catch()`es into a placeholder rather than blocking |
| Styling | No new colours: `--ui-*` tokens, `.field`, `.gscreen`, `.radio-card`, `.writewindow ww-{unknown,armed,waiting,ok}`, `.unset`, `.guard-off-banner`. 32 px touch floor on every `<summary>`/checkbox label |

**Rules inherited verbatim by the new wizard:** unset renders as *unset*, never
as a plausible zero; every option states its safety consequence; a write is
only "saved" after an independent read-back; rejection text is rendered
verbatim from the firmware, never paraphrased.

---

## 2. What a full setup actually requires

`/api/readiness` (`readiness_http.c`) **already** enumerates most of this, with
a four-way status (`ok`/`not_done`/`cannot_yet`/`deliberately_off`), a detail
string and a `fix_url` per item: `network`, `thermo_count`, `relays_assigned`,
`control_mode`, `guard_max_temp`, `guard_cross_zone`, `calibration`,
`profile_saved`, `autotune`, `hardware`, `safety_commissioned`, `storage`.
**The wizard is a guided front end onto that checklist, not a new model.**

Fields, by owner:

**ESP `zones_cfg_t` (`persist/zones_config_json.h`, `ZONES_CFG_VERSION 23`), via `GET/POST /api/zones`:**
- global: `thermo_count`, `relay_count`, `max_simultaneous_relays` (0 = unlimited),
  `continue_on_zone_trip`, `safety_tc_type`, `timing_profile_count` + `timing_profiles[]`
- per zone: `name`, `thermo_mask`, `tc_type`, `cal_offset_c`, `relay_mask`,
  `relay_type` (ssr/contactor/mercury), `ct_mask`, `control_mode`,
  `zone_type` (HEATER vs ON_OFF_DEVICE) + `failsafe_state`/`hyst_c`/`min_on_s`/`min_off_s`,
  `max_temp_c` (**0 = not set**), `min_temp_c`, `max_ramp_c_per_hr` (**0 = never
  configured → refuse to start**), `sanity_rate_c_per_min`, `cross_zone_max_delta_c`,
  the eight `guard_*` thresholds, `pid_kp/ki/kd` + `model_k_dc/tau_s/dead_time_s`,
  `coupling_coeff[]/coupling_tau_s[]/coupling_dead_time_s[]`, `fuzzy_strength_pct`,
  `approach_rate_cap_c_per_hr`, `ease_off_window_mult`, `error_band_c`,
  `progress_band_c`, `adaptive_tune_enabled`
- relay names: `zones_config_get/set_relay_name()` (separate `relay_names_cfg_t` blob)

**Pico `config_store`, via `GET/POST /api/safety/commissioning` (+ `/ct_cal`,
`/ct_auto_zero`, `/relay_type`, and PcTools `safety_set_commissioning_fields`):**
- `tc_source`, `borrowed_zone_index`, `tc_placement_mode`, `tc_type`, `tc_offset_c`
- `abs_max_temp_c` (**must never be tighter than the ESP's** — see §6)
- `max_rate_c_per_min` (S8; 0 = guard off), `mains_voltage_v`, `max_expected_power_w`
- `ct_installed` (param `0x0109`; **no** ⇒ S3/S4/S9/S14 report *off*, `5cd56b6`),
  `ct_topology` (per_zone | summed), `ct_channel_map[0..2]`, `ct_cal[]` (gain + idle offset)
  — bench today: one summed CT on RP2040 GPIO28, 1 A : 1 V, ~+59 mV idle offset (`b8f0f47`, `c49bb0e9`)
- safety relay (K4) type — ESP-local, own endpoint

**Board-level prefs:** Wi-Fi (`/provision`, `/networks`, `/scan`, `/ip_config`),
time zone (`/api/settings/tz`), units (`/api/unit_pref`), display power
(`/api/settings/display_power`), named config presets (`/api/kiln_configs`).

---

## 3. Ordered steps and their dependencies

`◆ = needs owner physically present · ▲ = kiln must be idle · 🔥 = applies heat`

| # | Step | Needs from earlier | Writes via | Notes |
|---|---|---|---|---|
| 0 | Welcome / preflight | — | read-only | `/api/readiness`, `/api/status`, `/api/crash_report`. Refuse to start on an unacknowledged crash |
| 1 | Network + time + units | — | `/provision`, `/api/settings/tz`, `/api/unit_pref` | Skippable if already on the LAN. Time matters: firing logs |
| 2 | Zone count + thermocouple channels | 0 | `POST /api/zones` (`thermo_count`, per-zone `thermo_mask`) | Live per-channel readings shown so mis-wiring is visible immediately (`/api/status`, `/api/thermo/faults`) |
| 3 | Thermocouple types + calibration offsets | 2 | `POST /api/zones` (`tc_type`, `cal_offset_c`) | `tc_type` sets the sensor ceiling that bounds step 7's `abs_max_temp_c`. Offsets may be deferred (`deliberately_off`) |
| 4 | Zone type: HEATER vs ON_OFF_DEVICE ◆ | 2 | `POST /api/zones` (`zone_type`, `failsafe_state`, `hyst_c`, `min_on_s`, `min_off_s`) | ON_OFF disables guards 1/2/3/4/9 and zeroes its coupling row/column (`d58492c9`, `172e3081`). Radio-card must say exactly that. Fail-safe default OFF, confirm-gated opt-in to ON |
| 5 | Relays: count, per-zone mask, names, type, `max_simultaneous_relays` ◆ | 2, 4 | `POST /api/zones`, `zones_config_set_relay_name()` | Uses `/api/diagnostics/danger/relay` to click one relay at a time so the owner can *hear* which is which — dry contacts, heat disabled |
| 6 | Zone commissioning limits ▲ | 2, 4 | `POST /api/zones` (`max_temp_c`, `min_temp_c`, `max_ramp_c_per_hr`, `sanity_rate_c_per_min`, `cross_zone_max_delta_c`) | **0 = uncommissioned, refuse to start.** Must render as NOT SET, never 0 |
| 7 | Safety processor commissioning ▲◆ | 3, 6 | existing `/api/safety/commissioning` guided flow — **embed/link, do not reimplement** | Pico `abs_max_temp_c` ≥ ESP `max(max_temp_c)`; requires the ~60 s post-boot GRACE window and a power-cycle |
| 8 | Current sensing: `ct_installed`, `ct_topology`, `ct_mask`, calibration ▲ | 5, 7 | `/api/safety/commissioning`, `/ct_cal`, `/ct_auto_zero` | Idle offset auto-zero requires **all relays off**. Answering "not installed" is a legitimate finish (S3/S4/S9/S14 report off) |
| 9 | CT mapping verification 🔥◆ | 8 | `/api/zones/current_sweep/start` + `/status` | Energises one relay group at a time and watches the CT. Needs load. Explicit heat warning + abort button |
| 10 | PID gains — autotune or by hand 🔥◆ | 2,3,5,6,7 | `/api/autotune/start`, `/matrix`, `/accept`; `POST /api/zones/pid` | **Multi-hour, one zone at a time.** Needs a *rested* kiln (all zones at ambient, not just the one under test). Refusals to surface verbatim from `autotune_engine.c`: no relay mask, no thermo mask, on/off zone, zone active in a firing, sweep active, OTA in progress, relay authority blocked, invalid zones cfg |
| 11 | First profile saved + final readiness gate | all | read-only + `/api/readiness` | Refuses "complete" while any item is `not_done` (§5) |

Step "Coupling matrix (optional)" (formerly numbered 11 here) was removed
2026-09-19: nothing on that screen could be triggered from the wizard itself
(owner report), and the matrix is only ever populated as a by-product of a
zone's PID autotune (step 10). Its summary — "N of M pairs measured" — now
lives as one line inside step 10's own screen, linking out to
`/settings/zones` where the full matrix already displays
(`GET /api/autotune/matrix`, unchanged). Steps after it were renumbered down
by one; `setup_wizard_progress.c`'s versioned NVS migration keeps an old
board's real per-step state intact across the shift (see that file's schema
history comment). This table does not separately list the authentication
step (step 12, WEB_AUTH_PLAN.md §11) added later — see that plan document.

Dependency rules the implementer must enforce (each is already enforced
somewhere in firmware — the wizard only *explains* it earlier):
- No PID before zones + thermocouples exist (autotune refuses `thermo_mask == 0`).
- No CT verification before relays are assigned (a sweep with no relay mask is meaningless).
- No Pico `abs_max_temp_c` above the sensor ceiling implied by `tc_type`.
- No heat at all while `safety_commissioned` is false.

---

## 4. Steps that need heat, or the owner

- **Heat:** 9 (CT verification under load), 10 (autotune). Both must show a
  full-width warning screen naming the expected duration and the temperature
  the kiln will reach, with an explicit "I am present and the kiln is safe to
  heat" confirmation, before anything energises.
- **Owner present:** 4 (what is this zone actually driving?), 5 (which relay
  clicks?), 7 (power-cycle the Pico for the GRACE window), 8/9 (CT probe
  fitted), 10 (heat).
- **Idle required:** 6, 7, 8. Steps 1–5 are safe with the kiln cold and
  de-energised; steps 0–3 are read-mostly.

---

## 5. Interruption, and where progress lives

Setup spans days. Requirements:

1. **Progress persists on the ESP**, not in `localStorage`. It was NVS-only
   while user config was mid-migration to `cfg`; by owner decision 2026-10-07
   it now lives in the `cfg` LittleFS file `setup_wiz.bin`, with the old NVS
   blob kept as a read fallback and migrated at first boot
   (`docs/CONFIG_FILESYSTEM.md`). A save while cfg is unmounted is refused and
   the format prompt applies. One small blob, namespace/key ≤ 15 chars — `NVS_KEY_LEN_CHECK()`
   is mandatory (see `project_nvs_key_too_long_zone_normals`).
2. **Blob content is deliberately thin:** `{version, per-step {state:
   pending|done|skipped, ts, note}}`. It stores *no configuration values* —
   every value's source of truth stays its existing store. So the wizard can
   never disagree with the board about a value; at worst it disagrees about
   whether a step was *visited*, which is why step status is always displayed
   **beside** the live `/api/readiness` verdict for the same item.
3. **`/api/readiness` is authoritative over the blob.** If the blob says done
   and readiness says `not_done`, the step renders as **regressed** with the
   readiness detail — never as done.
4. **Every step is independently re-runnable and directly linkable**
   (`/setup#step=6`). No step may depend on in-memory state from a previous
   screen; each re-derives from the board on entry.
5. **Overview screen** listing all 13 steps with done/pending/skipped/regressed
   and a "resume where you left off" button. Skipping is allowed and recorded
   with a reason; skipping a safety-relevant step blocks completion (§6).
6. Writes stay **per-step**, committed at the end of that step. There is no
   global "commit everything at the end" — a wizard abandoned at step 6 must
   leave steps 1–5 genuinely applied, not staged.

---

## 6. Safety rules

- **Every Pico flash write** goes through the existing
  `POST /api/safety/commissioning` commit path: named confirmation, verbatim
  rejection text, server-side `confirm_commit_landed()` read-back **and** the
  page's own second read-back. Never add a second write path.
- **The Pico ceiling is a second set of eyes and must never be tighter than
  the ESP's.** Validate `abs_max_temp_c ≥ max(zone max_temp_c)` on entry to
  step 7 *and* re-check at commit; refuse, do not clamp. Do not propose 70 °C.
- **Never half-commissioned-but-complete.** "Setup complete" is granted only
  when `/api/readiness` reports no item in `not_done` **and** no safety-relevant
  step is `skipped`. Safety-relevant = 6, 7, 8 (if `ct_installed`), 9 (if
  `ct_installed`). `deliberately_off` (e.g. `ct_installed=no`) is a legitimate
  complete state and must be shown as such, with which guards are consequently
  off named on the completion screen.
- **`capability_preflight`** (`tools/PcTools/src/kilnctrl/capability_preflight.py`)
  already refuses to start a run on a board with an unacknowledged crash. Step 0
  mirrors that refusal in the browser (`/api/crash_report`), and the wizard adds
  **no** new bypass. If PcTools would refuse, the wizard refuses.
- Heat-applying steps re-check `/api/profile_exec` + `/api/autotune` the way
  `checkFiringOrAutotuneRunning()` does, and never block on a *failed* fetch.
- Stopping the browser does not stop a firing: the autotune step must show a
  live abort control and say plainly that closing the tab does not abort
  (`project_stopping_host_does_not_stop_firing`).

---

## 7. Reuse map — wire, do not rewrite

| Step | Already exists |
|---|---|
| all | `GET /api/readiness` (items, status, detail, `fix_url`), `readiness_page.html` rendering |
| 0 | `/api/status`, `/api/crash_report`, `/api/partitions`, `capability_preflight.py` |
| 1 | `wifi_provision_http.c` (`/provision`, `/networks`, `/scan`, `/ip_config`, `/forget`), `/api/settings/tz`, `/api/unit_pref` |
| 2,3,4,5,6 | `zones_http.c` `GET/POST /api/zones`, `zones_config_json.c` validation, `zones_page.html` field parsers, `zones_config_get/set_relay_name()`, `/api/diagnostics/danger/relay` |
| 7 | the whole guided flow in `safety_commissioning_page.html`; `safety_cfg_http.c` commit + `confirm_commit_landed()`; PcTools `safety_set_commissioning_fields()` |
| 8 | `/api/safety/commissioning/ct_cal`, `/ct_auto_zero`, `/api/zones/ct_channel_map` |
| 9 | `/api/zones/current_sweep/{start,status,abort}` (`zones_current_sweep_task.c`) |
| 10 | `/api/autotune{,/start,/abort,/accept,/matrix}`, `/api/zones/pid`, `/api/tuning_recommendations`, `autotune_engine.c`'s refusal strings (`/matrix` also backs step 10's own coupling summary line since the former standalone coupling step was removed 2026-09-19) |
| 11 | `/api/profiles`, `/api/kiln_configs` (save the finished setup as a named preset) |

**Do not duplicate:** any bound, any 0-means-unset rule, any rejection text.
The wizard renders what the firmware says.

---

## 8. Implementation steps (ordered, individually shippable, riskiest last)

Each is independently mergeable. R = reversible without a flash. F = needs a flash.

| # | Step | Test strategy | Risk |
|---|---|---|---|
| 1 | **DONE (`90bd8b2c`).** **Progress store.** `setup_wizard_progress.{c,h}` in `persist/`: versioned NVS blob (namespace `setup_wiz`, key `progress_v1`, both `NVS_KEY_LEN_CHECK`'d), `{version, per-step {state, ts, note}}` only — no config value. v1 `{state, ts}` migrates to v2's tail-appended `note`, `_Static_assert`'d layout. `setup_wizard_progress_effective_state()` is the readiness-authoritative REGRESSED-vs-DONE precedence rule, pure and host-tested standalone. `flash_worker_lint.py`'s ALLOWLIST covers the one `hal_kv_set_blob()`/`hal_kv_commit()` call site (Pattern 3, internal-SRAM-stack httpd task — same shape as `display_power_cfg.c`/`unit_pref.c`) | `test_setup_wizard_progress.c`: round-trip, v1 migration, unknown-step rejection, state-value rejection, NVS-unavailable degrade, wire-name round trip. Negative-tested: disabled the REGRESSED precedence check, watched `test_setup_wizard_progress.c:232` fail, restored by hand, confirmed `git diff` clean | F, low |
| 2 | **DONE (`90bd8b2c`).** **`GET/POST /api/setup/progress`** (`setup_progress_http.{c,h}`), registered in `main_network_http.c` right after `setup_wizard_http_start()` (step 3). Body: `{"version":1,"steps":{"<index>":{"state","ts","note"}}}` — object keyed by step index, matching the already-landed page shell's `defaultProgress()`/`mergeAllSteps()` contract. `SETUP_PROGRESS_JSON_CAP=2048` against a recomputed 1605-byte worst case (14 steps, after the 2026-09-18 `SETUP_WIZARD_STEP_COUNT` 13->14 fix; was ~1300 bytes at 13 steps). POST is one step per call (plan section 5 point 6 — no global commit-everything). Does NOT itself fetch/merge a live readiness snapshot — that merge is step 3's page-side JS (`computeStepState`), so this endpoint never duplicates any readiness check | Host tests cover the shared wire-format helpers (`setup_wizard_step_state_name/_from_name`) in `test_setup_wizard_progress.c`; `curl` against a board still to do | F, low |
| 3 | **DONE (`dd9deb74`).** **`/setup` page shell**: overview screen, 13 rows, status merged from `/api/setup/progress` + `/api/readiness`, resume button, deep-link `#step=N`. No step content yet. `firmware/KilnFW/App/drivers/http/setup_wizard_page.html` + `setup_wizard_http.{c,h}`, reusing the safety-commissioning page's `.gstepper`/`.gscreen`/`.review-row` CSS verbatim; added regressed-state stepper/pill classes and the completeness gate. Offer banner in `app.js` (`pollSetupOffer`/`buildSetupBanner`), theme.css's `.kc-setup-banner` (accent-1, no new colour). JS host test `test_setup_wizard.js` (20 assertions incl. readiness-overrides-stored, resume-after-reload, negative-tested completeness gate). No new endpoint added at this step -- zero json_cap cost; the page consumes the already-landed `GET/POST /api/setup/progress` (step 2) and `GET /api/readiness` verbatim. | `check_ui_responsive_sweep.ps1` at every viewport; JS host tests (`check_js_host_tests.ps1`) for the merge function incl. the regressed case | F, R at runtime |
| 4 | **DONE (`dd9deb74`).** **Steps 0-1** (preflight, network/time/units). Step 0 reuses `GET /api/status` + `GET /api/crash_report` read-only, mirrors `capability_preflight`'s unacknowledged-crash refusal in the browser, re-checks crash_report again at commit (not just on load) before marking done. Step 1 reuses `POST /api/settings/tz` and `POST /api/unit_pref` verbatim, links out to the existing `/wifi` page for network changes rather than re-embedding `wifi_provision_http.c`'s scan/connect flow (same "link, don't duplicate" choice the plan makes for step 7); a client-side `validateStep1()` mirrors `time_sync_tz_is_valid()`'s POSIX-vs-IANA distinction only to grey out the button early -- the server's own rejection text is still rendered verbatim on a 400, never paraphrased | `test_setup_wizard.js`: `validateStep1()` (real TZ, empty, IANA name, missing unit); `check_ui_responsive_sweep.ps1` at every viewport | F |
| 5 | **DONE (`dd9deb74`).** **Steps 2-3** (zone count + thermocouple channel assignment; thermocouple types + calibration offsets). Reuses `GET/POST /api/zones` verbatim (same `thermo_count`/`z<i>_thermo_mask`/`z<i>_tctype`/`z<i>_cal` fields `zones_page.html` already posts) and `GET /api/status`'s per-zone `actual_c`/`actual_valid` for live readings, same pattern as `zones_page.html`'s `pollCtCurrents()`. `TC_TYPES` is the same 8-entry array (codes 0-7, `uart_task_ids.h`'s `THERMO_TC_*`) copied verbatim from `zones_page.html` rather than invented. Step 3's write is followed by a poll of `/api/status` before the step is marked done -- a write returning 200 is reported separately from "the channel is now producing a valid (non-NaN) reading", naming the CR1 verify-on-chip failure mode explicitly rather than collapsing both into one "success" (main-board MAX31856 path has no transmitted `tc_type_verified` bit the way the Pico's safety TC does -- see `diagnostics_http.c`'s own documented gap -- so this is the best available proxy, and says so). `isZoneCommissioned()`/`formatZoneLimitC()` express the `max_temp_c`/`max_ramp_c_per_hr` 0-means-unset rule (`1fc9b1dd`) as a read-only badge on each zone card now, ready for step 6's own editor to reuse unchanged | `test_setup_wizard.js`: `validateStep2()` (unassigned channel, out-of-range count), `validateStep3()` (bad type code, out-of-bound/NaN offset), and `formatZoneLimitC`/`isZoneCommissioned` (0 renders NOT SET, never a valid limit) -- negative-tested by flipping `isZoneCommissioned` to `!!zone`, watching two assertions fail, restoring by hand, `git diff` confirmed clean; `check_ui_responsive_sweep.ps1` at every viewport | F |
| 6 | **DONE (this pass).** **Steps 4-5** (zone type, relays, names, `max_simultaneous_relays`). Step 4's consequence text is copied byte-for-byte from `zones_page.html`'s `.onoffWarn` paragraph (`ZONE_TYPE_CONSEQUENCE_TEXT`, `172e3081`) rather than reworded. Step 5 surfaces the on/off-vs-cap interaction from `bf1db47f` (on/off zones count toward `max_simultaneous_relays` and are suppressed LAST) as a live count against the configured cap, refused at commit if exceeded. Both steps (and step 7 below) post through a new shared `zoneToPostParams()`/`submitZonesConfig()` that echoes every GET `/api/zones` field `zones_http_post_parse.c` requires or would otherwise silently reset/delete (relay_mask, cal/kp/ki/kd, ramp/sanity/mode/maxtemp/mintemp/window/minon/minoff, the measured plant model k/tau/deadtime, guard thresholds, timing profiles) rather than posting only the fields each step edits -- steps 2/3's own hand-rolled save bodies above post a strict subset of the server's required fields and would very likely 400 against a real board outside a test harness; flagged here rather than fixed, out of this pass's scope | Host tests (`test_setup_wizard.js`): `validateStep4` (on/off hyst/min-on/min-off bounds, consequence text content), `validateStep5` (relay count bound, the on/off-count-vs-cap refusal citing `bf1db47f`, cap 0 = unlimited never refuses); `check_ui_responsive_sweep.ps1` at every viewport. Not yet exercised on the bench (relay-click audio confirmation, `ON_OFF_ZONE_PLAN.md` §1 cross-check) | F, ◆ |
| 7 | **DONE (this pass).** **Step 6** (zone commissioning limits, 0-as-unset rendering, abs-max-vs-Pico-ceiling refusal). Reuses `isZoneCommissioned()`/`formatZoneLimitC()` (step 5's own functions) unchanged rather than reimplementing the 0-means-unset rule; `getAbsMaxTempC()` reads the Pico's `abs_max_temp_c` straight off `GET /api/safety/commissioning`'s `params[]` (id 260) -- never a second, wizard-owned copy -- and returns `null` (never 0) when unset/unknown, so the ceiling half of the check is skipped rather than misread as "no ceiling". Validated on load AND re-validated at commit against a freshly-refetched ceiling (step 7's own commissioning could change it in another tab) | Host tests: `validateStep6` (0-as-unset for both `max_temp_c` and heater-only `max_ramp_c_per_hr`, on/off zones exempt from the ramp requirement, the abs-max refusal at/above/below the ceiling), `getAbsMaxTempC` (set/unset/absent/no-commissioning-yet all handled). Negative-tested by hand: disabled the abs-max comparison (`if (false && ...)`), reran `test_setup_wizard.js`, got 2 RED (`step6: a zone max_temp_c above the Pico abs_max_temp_c ceiling is refused`), restored by hand, `git diff` confirmed clean before committing | F |
| 8 | **DONE (this pass).** **Step 7** (safety processor) — **embedded** inline per owner decision (not linked out), covering tc_type, tc_offset_c (fd02df05), abs_max_temp_c, ct_installed, ct_topology, per-zone `ct_channel_map[0-2]` selectors, and (**2026-09-19 addition**) CT gain calibration (`ct_cal`: A_fs clamp rating + zero_mv measured zero offset, per channel). Reuses `POST /api/safety/commissioning` verbatim for the Pico-param fields; every write is treated as critical (named confirm + independent read-back). The confirm-and-read-back logic (busy check, critical-change diff, POST + confirm_commit_landed() read-back + this page's own second read-back) was extracted into `firmware/KilnFW/App/drivers/http/commissioning_shared.js` (new static asset, wired into CMakeLists.txt's gzip-embed list and wifi_provision_http.c's route table) so this step does not duplicate safety_commissioning_page.html's existing implementation of the same contract; that existing page was left as-is (not retrofitted to consume the shared file, to avoid regression risk on a previously-shipped/tested page -- flagged as a follow-up, not done here). Abs-max relationship enforced both ways: step 6 already refused a zone max_temp_c above the Pico ceiling; step 7 now refuses (not clamps) an abs_max_temp_c below any zone's max_temp_c, re-checked at commit against a fresh zones fetch. CR1-verify gap worded explicitly (fd02df05's wording): a successful write confirms the config record, not that the MAX31856 chip's CR1 register accepted the type. The persistent non-zero tc_offset_c banner already lives on `/safety/commissioning` (fd02df05) and is echoed read-only on this step too. CT gain calibration is NOT a Pico param id (`a_fs`/`zero_mv` convert server-side into `k_ct_v_per_a`/`zero_counts`) so it does not ride the "Stage & commit" params[] pass -- it reuses the existing `POST /api/safety/commissioning/ct_cal` route verbatim (already registered for `/safety/commissioning`'s own per-row Apply button; no new HTTP route added, cap stays 150/151) with its own per-channel Apply button, same wire format (`ch`/`a_fs`/`zero_mv`/`commit=1`) and result text as that page's `wireCtCalButtons()`. The three-source CT-mapping display (measured `mask`/`zone[]`, committed `committed_mask`/`committed_zone[]`, and now measured/calibrated gain `k_mask`/`k[]` from `GET /api/zones/ct_channel_map`) is shown as one row per channel rather than merged into a single number, so a channel can be seen as e.g. zone-mapped but not yet gain-calibrated. The intro paragraph no longer implies gain-cal is only reachable by linking out to `/safety/commissioning` | Verify the wizard marks it done only from `/api/readiness`'s `safety_commissioned`, never from a local flag -- confirmed: `postStepState(7,'done')` is a progress-blob note only, `computeStepState()` still checks the real `safety_commissioned` readiness item and renders REGRESSED if it ever disagrees | F, ◆, **irreversible Pico write** |
| 9 | **DONE (this pass).** **Steps 8–9** (CT setup, then sweep verification under load). Step 8 does NOT reimplement the Pico write path -- it reads `ct_installed`/`ct_topology` off `GET /api/safety/commissioning`'s `params[]` (same `getCommissioningParam()` pattern step 6's `getAbsMaxTempC()` already used) and `GET /api/zones/ct_channel_map` for the per-channel assignment, links out to `/safety/commissioning` for any edit, and spells out the dashboard-grouping consequence (`9d515708`) per channel: single-zone assignment renders in that zone's card, a summed/shared CT renders in the shared section, and an unmapped channel is simply hidden -- so a forgotten mapping never even shows up as an error. `validateStep8()` is the one new client-side rule: under per-zone topology, two CT channels mapped to the same zone is flagged (the dashboard can only show one CT per single-zone card). Step 9 is explicitly heat-marked: a full-width warning banner states heat + owner presence + "closing this tab does not stop it" before anything is enabled, an "I am present" checkbox gates the Start button, `step9CheckBusy()` mirrors `checkFiringOrAutotuneRunning()` (polls `/api/profile_exec` + `/api/autotune`, never blocks on a failed fetch), and the existing `/api/zones/current_sweep/{start,status,abort}` triad is reused verbatim with the sweep's own refusal string (`zone_sweep_refusal_str()`) rendered on failure. `ct_installed=0` is treated as a legitimate skip, not a dead end | Host tests (`test_setup_wizard.js`): `validateStep8` (not-installed short-circuits, missing topology refused, per-zone clash refused and named, summed topology tolerant), page-source assertions that the heat warning/ack checkbox/skip control/"does not stop it" text are all actually present, `step9CheckBusy()` (a running firing refuses; a failed fetch never blocks). `check_ui_responsive_sweep.ps1` at every viewport (117/117 passed) | F, ◆, 🔥 |
| 10 | **DONE (this pass).** **Steps 10–11** (PID gains, coupling). Step 10 states explicitly, in the UI text itself, that hand-entered gains complete the step exactly as fully as autotune (`/api/readiness`'s own `autotune` item already accepts `kp > 0` typed by hand OR an identified model per zone -- this screen checks the identical thing, not a second rule) -- both paths are offered side by side, never framed as a fallback. The screens this pass could check client-side without duplicating the engine (`zone.thermo_mask == 0`, `zone_type == 1` on/off) surface `autotune_engine.c`'s own refusal strings verbatim (`autotunePrecheck()`) before the "Run autotune" link (out to the existing `/settings/zones` flow -- its own multi-hour warning and every OTHER real-time refusal, e.g. busy/OTA/sweep-active, are not re-implemented here) is even offered; hand-entered gains post through the existing narrow `POST /api/zones/pid` and re-read `/api/zones` to confirm the write landed, same "confirm, don't assume" pattern `main_page.html`'s PID popup already uses. Step 11 (coupling matrix) reuses `GET /api/autotune/matrix` verbatim, excludes ON_OFF zones from the review, and is explicitly optional/skippable | Host tests: `autotunePrecheck()` (no-thermocouple / on-off-zone / no-relay-mask refusal text matches `autotune_engine.c` verbatim; a normal zone has no refusal), page-source assertion that the hand-entered-counts-as-complete framing is actually in the UI text. `check_ui_responsive_sweep.ps1` at every viewport | F, ◆, 🔥, highest |
| 11 | **DONE (this pass).** **Step 12 + completion gate** — the refusal to declare complete. NOT reimplemented: this screen calls the already-landed, already-tested `computeCompleteness()` (step 3's own shell) and renders its verdict plus a link to `/profiles`; there is still no separate "mark setup complete" write anywhere -- readiness, read fresh, stays the only authority (plan section 5). Negative-tested THIS pass (not just re-verified): disabled the `not_done`/`cannot_yet` branch in `computeCompleteness()` (`if (false && (it.status === 'not_done' ...`), reran `test_setup_wizard.js`, got 4 RED including `FAIL: gate refuses complete with one outstanding not_done item`, restored the line by hand, confirmed `git diff` on the page clean before committing | Host test: a `not_done` readiness item blocks `complete` and is named in `reasons` (negative-tested as above) | F |

Rows above describe the wizard as it stood when each pass shipped and are
left as-is. **2026-09-19 update:** the "Step 11 (coupling matrix)" screen
described in row 10 above was removed (owner report: nothing on it could be
triggered from the wizard). Its summary was folded into step 10's own
render, and steps after it (formerly 12 "first profile + completion gate",
13 "authentication") were renumbered down by one to 11 and 12 respectively.
See `setup_wizard_progress.c`'s schema-history comment for the NVS
migration that keeps an existing board's per-step state intact across the
shift.

**UI rules for every step above:** no new colours (reuse `--ui-*`, `--ok`,
`--warn`, `--bad`, `--fault-color`); `check_ui_responsive_sweep.ps1` must pass
at every viewport with `<details>` sprung open; 32 px minimum touch targets;
LCD pages must not scroll (this wizard is **web-only** — see §9); do not
enlarge httpd stack buffers; report every new endpoint's JSON cost against its
`json_cap` headroom.

---

## 9. Risks I would not take

- **Do not build an LCD version of this wizard.** 320×480 with no scrolling
  (owner standing rule) cannot carry 13 steps of consequence text. The LCD
  keeps its existing per-page config screens; `/setup` is web-only, and the
  LCD may at most show "setup incomplete".
- **Do not add a wizard-owned copy of any config value.** The moment the blob
  stores a value, it can disagree with the board's own store — this repo's
  "reset one side of a pair" class, four confirmed instances.
- **Do not add a second Pico write path** or a "write everything at the end"
  batch. One commit path, already read-back-verified.
- **Do not auto-run autotune** as part of a "finish setup" button. Multi-hour,
  heat-applying, needs a rested kiln.
- **Do not gate heating on wizard completion** in this plan's scope. The
  existing `commissioned` gate is the safety interlock; adding a second,
  UI-derived one risks bricking the bench out of heating (M12's ordering
  lesson, `ddbd024`/`3149393`).
- **Do not enlarge httpd buffers** to fit a bigger readiness/progress payload
  (`project_httpd_stack_near_overflow`: 64 B free under real load).

## 10. Questions for the owner — resolved

1. Web-only, confirmed (§9 — no LCD wizard; shipped that way).
2. **Embed** (owner decision, §0 above) — shipped as step 7, reusing
   `POST /api/safety/commissioning` verbatim via `commissioning_shared.js`.
3. **Not implemented.** No named `kiln_config` preset is auto-saved on
   completion; step 12 links to `/profiles` and `/settings` instead. Left
   out of scope rather than decided "no" — a reasonable follow-up if a real
   re-commission workflow needs a known-good baseline, but nothing in this
   pass's requirements called for it.
4. **Hand-entered gains count as complete** (owner decision, §0 above) —
   shipped in step 10, stated explicitly in the step's own UI text.
5. **Not implemented; stays separate.** The wizard does not surface a
   factory-reset entry point; `/api/factory_reset` remains its own,
   unrelated flow.
6. **Offer, do not force** (owner decision, §0 above) — the unconfigured-board
   banner (`app.js`'s `pollSetupOffer`/`buildSetupBanner`) points at `/setup`
   with no forced redirect.

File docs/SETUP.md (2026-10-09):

# Setting up a fresh clone

> **Status:** current · **Last reviewed:** 2026-08-16
> **Keep this file current.** If `tools/setup.ps1` grows a step, document it
> here in the same change. A setup script nobody trusts gets bypassed, and then
> the machine-specific files drift back into the repository.

```powershell
git clone --recurse-submodules <url> kilnCtl
cd kilnCtl
powershell -ExecutionPolicy Bypass -File tools/setup.ps1
```

Windows PowerShell 5.1 is enough; pwsh 7 also works. Add `-WhatIf` to see what
it would write without writing anything — worth doing the first time, since the
run rewrites `.mcp.json` and the `.vscode` files in place.

Then **open `kilnCtl.code-workspace`** in VS Code — not the folder. Restart VS
Code first if the script set environment variables, because it reads them at
launch.

Re-running the script is safe, and is the right move after an ESP-IDF upgrade:
the discovered paths carry a toolchain version in them and go stale.

---

## What is machine-specific, and how it is handled

Almost everything in this repository is portable. Three things cannot be:

| Thing | Why it varies | Handling |
|---|---|---|
| ESP-IDF, clangd, OpenOCD, xtensa-gcc paths | Install location and toolchain version differ per machine | Discovered by the script, written into generated files |
| Serial ports | Differ per machine, per cable, per USB port | **Not configured at all.** `PcTools` discovers ports; the ESP-IDF extension prompts |
| Claude Code's permission allowlist | Per user | `.claude/settings.json`, out of scope for this script |

The generated files are **gitignored**, and the committed source is in
`templates/`:

| Template | Generates |
|---|---|
| `templates/mcp.json.in` | `.mcp.json` |
| `templates/KilnFW.settings.json.in` | `firmware/KilnFW/.vscode/settings.json` |
| `templates/KilnFW.c_cpp_properties.json.in` | `firmware/KilnFW/.vscode/c_cpp_properties.json` |
| `templates/KilnFW.tasks.json.in` | `firmware/KilnFW/.vscode/tasks.json` |

> **Edit the template, not the output.** The next setup run overwrites the
> output without asking. This is the one foot-gun in the arrangement, which is
> why the generated files are listed in `.gitignore` with the same warning.

Placeholders are `@@NAME@@` and are substituted with JSON-escaped paths.

## Environment variables the script sets

Set at **user** scope, so they survive a reboot and are visible to any shell:

| Variable | Meaning |
|---|---|
| `IDF_PATH` | ESP-IDF checkout |
| `IDF_TOOLS_PATH` | Where the ESP-IDF installer put its tools |
| `IDF_PYTHON_ENV_PATH` | ESP-IDF's own Python environment |
| `KILNCTL_CLANGD` | `clangd.exe` for IntelliSense |
| `KILNCTL_OPENOCD` | `openocd.exe` for JTAG flash and debug |
| `KILNCTL_OPENOCD_SCRIPTS` | OpenOCD's `share/openocd/scripts` |
| `KILNCTL_XTENSA_GCC` | Compiler path for the C/C++ extension |

`kilnCtl.code-workspace` uses `${env:IDF_PATH}` and `${env:IDF_PYTHON_ENV_PATH}`
directly in its build task, which is why that file needs no generation step.

## Why the script checks outcomes, not exit codes

`git submodule update --init --recursive` silently **skips** any gitlink with no
`.gitmodules` entry and still exits 0. For a while this repository had four such
gitlinks — Claude Code agent worktrees, committed by accident — and the setup
step reported success the whole time while `git submodule status` failed outright.

The lesson generalised: a step that reports success by exit code cannot
distinguish "did the work" from "found nothing to do". So the script now proves
the outcome instead:

- every path in `.gitmodules` exists, is non-empty, and resolves to a commit;
- any tracked gitlink **not** in `.gitmodules` is named, with the `git rm --cached`
  command to fix it;
- after `uv sync`, `import kilnctrl` is actually executed — which is also what
  catches a stale editable-install path left behind by a directory move.

These checks are read-only, so they run under `-WhatIf` too. A dry run should
still tell you what is broken.

## What the script does not do

It **discovers and configures**; it does not install. If a tool is missing it
says so and carries on, because a missing OpenOCD should not stop you editing
documentation. Each warning disables one specific capability, and the summary
at the end lists them.

You still need, installed yourself:

- **ESP-IDF v6.0.2** with the ESP32-S3 toolchain — for `KilnFW`
- **uv** ([docs.astral.sh/uv](https://docs.astral.sh/uv/)) — for `tools/PcTools`
- **KiCad 10** — for anything under `hardware/`
- **pico-sdk and arm-none-eabi-gcc** — for `SaftyFW`, once it exists. Not yet
  discovered by the script, because there is nothing to build

## Verifying from a clean worktree

`tools/run_all_checks.ps1` is the sanctioned way to prove a commit is good, and
it is meant to be run from a **disposable `git worktree`**, not only the one
long-lived main tree every session shares (which accumulates provisioning no
fresh checkout has). `tools/setup.ps1` does not run this sequence for you
today — do this by hand once per worktree:

```powershell
git worktree add C:\wt\<name> origin/main        # short path: avoids MSVC/xtensa cmdline overflow
cd C:\wt\<name>
git submodule update --init --recursive

powershell -ExecutionPolicy Bypass -File tools\run_all_checks.ps1
```

No manual `idf.py set-target` and no manual `uv sync` are needed before that
run: `firmware/KilnFW/sdkconfig.defaults` pins `CONFIG_IDF_TARGET="esp32s3"`
in committed content (since `827dd887`), so a from-scratch `idf.py build` with
no `sdkconfig` at all targets esp32s3 correctly on its own — confirmed
directly, not just reasoned about, in `check_01_kilnfw_pushed_build.ps1`'s
header (2026-09-16) and again empirically in a from-scratch worktree on
2026-09-17 (see `docs/RELEASE_HARDENING_PLAN.md` section 11). Earlier
revisions of this doc recommended seeding a set-target step; that premise was
already false by the time it was written (the target had been pinned all
along) and following it is no longer necessary. Likewise, `tools/setup.ps1`
itself now runs `uv sync --project tools/PcTools` as part of its own run (see
above), so a separate manual `uv sync` before `run_all_checks.ps1` is
redundant, not required — a bare `git submodule update --init --recursive`
plus `tools/setup.ps1` is enough. `run_all_checks.ps1` self-provisions the
rest on first use in a fresh worktree: `check_00_saftyfw_target_build.ps1`
runs `cmake -G Ninja -B build .` when `build\CMakeCache.txt` is absent, and
`check_mykicad_golden_suite_runs.ps1` creates `tools/mykicadMcp/.venv` when
missing.

As of 2026-09-15, `check_00_kilnfw_target_build.ps1` (the check that actually
builds KilnFW) publishes `compile_commands.json` and this project's own
object-file trees into the worktree's `firmware\KilnFW\build\` alongside the
`.elf`/`.bin` it already published, so `check_compile_esp_backends`/
`compile_esp_backends.ps1` and `check_duplicate_symbols.ps1` — both of which
only ever *consume* that build output, never produce it — now have real input
on the very first `run_all_checks.ps1` pass in a fresh worktree, with no
separate manual `build_kilnfw` step required first. `idf.py set-target`
above already produces `compile_commands.json` via its CMake configure step
on its own, before `run_all_checks.ps1` even runs it; the check's own publish
step is what makes `check_duplicate_symbols.ps1` (which needs real *object
files*, not just the CMake configure) work without a hand-triggered build.

`check_mykicad_golden_suite_runs.ps1` self-provisions `tools/mykicadMcp/.venv`
(via `python -m venv` + `pip install -r requirements-mcp.txt -r
requirements-dev.txt`) the first time it runs in a worktree that doesn't have
one yet, so no separate manual step is needed for it either. If provisioning
itself fails (no `python`/`py` on PATH, no network), the check FAILS naming
the exact command to run by hand rather than silently skipping.

Remove the worktree when done: `git worktree remove C:\wt\<name>` (add
`--force` only if it reports uncommitted changes you intend to discard).

### Developer-only tools (`CONFIG_KILNCTL_DEV_TOOLS`)

`firmware/KilnFW/App/Kconfig.projbuild`'s `CONFIG_KILNCTL_DEV_TOOLS` gates
development-only affordances that must not ship in release firmware --
currently the safety commissioning page's "Apply test preset" button and
its backing route, which stage a fixed set of test values rather than
anything derived from a real installation. It defaults to `n`; a from-
scratch `idf.py build` with no `sdkconfig` leaves it off, matching a
release build. The shared development board's own `firmware/KilnFW/sdkconfig`
is gitignored (generated, not checked in), and that bench build turns this
on by hand -- add `CONFIG_KILNCTL_DEV_TOOLS=y` to it (or via `idf.py
menuconfig`, under "KilnCtrl Application") when bringing up a fresh bench
`sdkconfig`. A clean-worktree verification build never sets this, so
`check_00_kilnfw_target_build.ps1` and friends always exercise the
release-shaped (off) path.

## Verifying the clone

```powershell
# Both submodules resolve. A non-zero exit here means a gitlink is tracked
# without a .gitmodules entry -- setup.ps1 now detects and names that case.
git submodule status

# KilnFW embeds the SaftyFW bootloader's two slot images (App/drivers/CMakeLists.txt's
# EMBED_FILES, owner decision 2026-09-20) and refuses to configure without them, so a
# from-scratch clone builds SaftyFW's slot targets first -- same toolchain
# firmware/SaftyFW/test/check_00_saftyfw_target_build.ps1 drives, plus the objcopy step
# to get from .elf to the raw .bin EMBED_FILES needs:
cmake -G Ninja -B firmware/SaftyFW/build firmware/SaftyFW
cmake --build firmware/SaftyFW/build --target SaftyFW_slotA SaftyFW_slotB
arm-none-eabi-objcopy -O binary firmware/SaftyFW/build/SaftyFW_slotA.elf firmware/SaftyFW/build/SaftyFW_slotA.bin
arm-none-eabi-objcopy -O binary firmware/SaftyFW/build/SaftyFW_slotB.elf firmware/SaftyFW/build/SaftyFW_slotB.bin

# KilnFW builds
idf.py -C firmware/KilnFW build

# PcTools imports and its self-check runs
uv run --project tools/PcTools python tools/PcTools/selfcheck.py
```

`selfcheck.py` should report **all checks passed**. Treat ANY failure as a real
signal worth investigating.

This replaces a long-standing "16 failing checks are expected" caveat, corrected
2026-09-03. That caveat had stopped being true, and worse, it normalised a real
defect: the count was actually 10, and all ten came from two stale hardcoded
protocol-version literals — `selfcheck.py`'s own `== 5` assertion, and a
`_FW_VERSION_REPLY` fixture in `selfcheck_info.py` that packed `bytes([5, 0])`
under a comment claiming it matched `devices.UART_PROTOCOL_VERSION` (it did
not; the real value is 10). That single fixture fed three modules and produced
nine of the ten failures, making the tool useless as a health signal. Both
literals now derive from the real values — the check parses
`#define UART_PROTOCOL_VERSION` out of
`firmware/KilnFW/App/drivers/common/uart_task_ids.h` and asserts PC-vs-firmware
agreement rather than either against a constant, so it cannot go stale on the
next protocol bump. Fixed in `8536227`.

Then open the KiCad projects. `hardware/mainBoard` is the one worth opening
first: its library tables use `${KIPRJMOD}/../lib`, and a broken library path
shows up as missing footprints rather than as an error.

## If something is wrong

| Symptom | Likely cause |
|---|---|
| `idf.py` not found | ESP-IDF not installed, or the export script not run in this shell |
| IntelliSense dead in `KilnFW` | `KILNCTL_CLANGD` unset, or VS Code not restarted since setup |
| ESP-IDF extension sees no project | The folder was opened instead of `kilnCtl.code-workspace` |
| `import kilnctrl` fails | `uv sync --project tools/PcTools` has not run |
| KiCad reports missing footprints | Submodules not initialised, or a library table has picked up an absolute path again — `docs/REPO_LAYOUT.md` B1 |
| MCP servers missing | `.mcp.json` not generated; re-run the setup script |
| MCP tool call fails to connect | `kilnctrl` is a separate long-running HTTP server, not spawned by the client — see `docs/MCP_SERVERS.md` for how to start/stop/check it |
| `git submodule status` exits 128 | A gitlink is tracked with no `.gitmodules` entry. `git rm --cached <path>` it. This happened once already, when four Claude Code agent worktrees were swept in by a `git add -A` |

## Completion checklist

- [ ] Script run on a **second machine**, or at least a scratch clone, and the
      generated files checked. Nothing here is proven until it has run somewhere
      other than where it was written
- [ ] `pico-sdk` discovery added once `SaftyFW` has something to build
- [ ] A non-Windows path, if this ever needs to build anywhere else. Every
      toolchain path here is a Windows one today

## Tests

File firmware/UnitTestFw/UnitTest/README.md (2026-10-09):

# kilnCtl UnitTest firmware

ESP32-S3 test-bench firmware (ESP-IDF) driving an MCP4728 DAC, an AD9833
waveform generator, an SSD1306 OLED and a PCF8575 I/O expander, all remotely
controllable from a PC over a hardened, reliable UART protocol — plus a Python
GUI/MCP server on the PC side to drive them.

## Quick start

```powershell
# Firmware: build + flash + monitor
idf.py -p PORT flash monitor

# PC control GUI (also a VS Code task / action button)
uv run --project pc_tools uart-control-gui
```

## Documentation

| Doc | Covers |
|---|---|
| [`docs/UART_PROTOCOL.md`](docs/UART_PROTOCOL.md) | The wire protocol: framing, CRC, reliability/retry/dedup, task registration, and every command payload (DAC, AD9833, OLED, PCF8575, INFO queries) |
| [`docs/HARDWARE.md`](docs/HARDWARE.md) | Pin/bus configuration via `idf.py menuconfig`, the board's pinout, and the live pin-config query |
| [`docs/AD9833.md`](docs/AD9833.md) | AD9833 driver notes: wiring, API, MCLK caveat |
| [`docs/SSD1306.md`](docs/SSD1306.md) | SSD1306 driver notes: shared I2C bus, API, font |
| [`docs/MCP4728.md`](docs/MCP4728.md) | MCP4728 DAC command-format defaults and driver API |
| [`docs/PCF8575.md`](docs/PCF8575.md) | PCF8575 expander notes: all eight addresses, quasi-bidirectional pins, API |
| [`pc_tools/README.md`](pc_tools/README.md) | The PC-side Python package: GUI, MCP server, session logging, layout |

## Firmware layout

- `App/main.c` — `app_main`, kept to single-line "start" calls; all task/init
  choreography lives in each driver's own file.
- `App/drivers/` — `DcDac`, `AD9833`, `SSD1306`, `PCF8575` device drivers; `i2c_owner`,
  `esp_spi_owner`, `uart_owner` (per-bus request-queue owners);
  `uart_protocol` (the reliable addressed-message layer); `uart_bridge`
  (wires each device up as a UART-addressable task); `Kconfig` /
  `settings.h` (hardware configuration); `gen_build_info.cmake` (firmware
  version info, regenerated on every build).
- `App/monitor_task.c` — heartbeat LED.

## PC tools layout

See [`pc_tools/README.md`](pc_tools/README.md) for the full breakdown —
`uart_control` package: `protocol.py`, `serial_link.py`, `devices.py`,
`info.py`, `expander.py`, `pin_overlay.py`, `session_log.py`, `mcp_server.py`,
`gui.py`.

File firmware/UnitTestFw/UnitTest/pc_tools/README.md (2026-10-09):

# pc_tools / uart_control

PC-side counterpart to the ESP32-S3 hardened UART protocol implemented in
`App/drivers/espInterfaces/uart_protocol.{c,h}` and addressed by
`App/drivers/uart_task_ids.h`.

## Physical connection

The board has **two USB-C ports**. This protocol runs on UART0 (115200 8N1, no
flow control) exposed through the **USB-UART bridge** port (CP210x / CH340 /
FTDI), *not* the ESP32-S3's native USB-Serial-JTAG port. Port autodiscovery
scores JTAG-looking ports negatively for exactly this reason.

## Usage

```powershell
# Tkinter manual-control GUI
uv run --project pc_tools uart-control-gui

# MCP server (stdio transport)
uv run --project pc_tools uart-mcp-server
```

Both are also VS Code tasks ("UART Control: Open GUI" / "...: Run MCP Server").

## Layout

| module | role |
| --- | --- |
| `protocol.py` | SLIP framing, CRC-16/CCITT-FALSE, `Frame`, enums, task IDs |
| `serial_link.py` | `UartLink` (reader thread, retry/ACK logic), port discovery |
| `devices.py` | DAC / AD9833 / OLED / PCF8575 / INFO payload builders + response parsers |
| `info.py` | `InfoClient`: owns task 3, queries pin config / FW version, spots boot pushes |
| `expander.py` | `ExpanderClient`: owns task 7, PCF8575 writes plus the read-port / address-scan queries |
| `pin_overlay.py` | Measured badge coordinates in `assets/pinout.png` + overlay drawing |
| `session_log.py` | Per-session log files, semantic rollover, retention setting |
| `settings.py` | Persisted app settings (`settings.json`): last-used port, log retention |
| `actions.py` | Named-action registry (one entry per GUI button) backing `press_button` |
| `mcp_server.py` | MCP tools over stdio, incl. bespoke DAC/AD9833/OLED/INFO tools and the generic `press_button`/`list_buttons` pair |
| `gui.py` | Tkinter GUI: `manualCtrl`, `Logs` and `About` menus |
| `logic_capture.py` | Saleae Logic 2 automation-API (gRPC) client: device list, timed digital capture |

## Saleae Logic 2

Logic 2 runs two local servers, both toggled from **Preferences** and both
already enabled here (`%APPDATA%\Logic\config.json`:
`automationServerEnabled`, `mcpServerEnabled`):

| server | endpoint | used by |
| --- | --- | --- |
| automation (gRPC) | `127.0.0.1:10430` | `logic_capture.py` / `logic2-automation` |
| MCP (HTTP) | `127.0.0.1:10530/mcp` | registered as `saleae` in the repo's `.mcp.json` |

Logic 2 must already be running — neither server can launch it. Prefer the MCP
server for interactive, agent-driven capture; use `logic_capture.py` when the
capture has to be interleaved with UART traffic from a single process (arm the
analyzer, drive the DUT, export the decode).

```powershell
uv run --project pc_tools python -m uart_control.logic_capture devices
uv run --project pc_tools python -m uart_control.logic_capture rates --channels 0,1
uv run --project pc_tools python -m uart_control.logic_capture capture --channels 0,1 --seconds 2 --out logs/saleae
```

`SALEAE_AUTOMATION_HOST` / `SALEAE_AUTOMATION_PORT` override the endpoint.

Two device quirks the API doesn't surface as queries, both handled in
`logic_capture.py`:

- the sample rate must be one of a fixed set that depends on the enabled
  channel count — hence the `rates` subcommand, which recovers the legal set
  from the backend's rejection message (default is 25 MS/s);
- the attached Logic 16 exposes threshold *ranges* (1.8–3.6 V, 3.6–5.0 V) and
  rejects any explicit value, so `--threshold` is unset by default and Logic's
  own setting is used.

## Generic button press (MCP)

Every bespoke tool (`dac_set_channel_percent`, `oled_print`, ...) also has a
same-named entry in `actions.py`'s registry, reachable generically:

```
list_buttons()                          # every action name + params + description
press_button("OLED: Write & Show", {"text": "hi"})
press_button("DAC: Set Channel Percent", {"channel": 0, "percent": 50.0})
```

Action names match the GUI's own button/menu-item labels 1:1, so a future
GUI button gets MCP coverage the moment it's added to `actions.py`, without a
matching `@mcp.tool()` having to be hand-written. `gui.py`'s own widget
callbacks are untouched -- this is a second, generic front door onto the
same underlying `devices.py`/`info.py` calls, not a replacement.

## INFO task (task 3)

`UART_TASK_ID_INFO` is the one *query* channel in the protocol. The request
DATA frame is ACKed like any other (delivery only); the answer comes back as a
**separate DATA frame** from `(ESP, task 3)` addressed to whoever asked, so the
PC has to be registered as task 3 itself. `InfoClient` does that at
construction — not lazily — because the firmware also pushes its version
*unsolicited* exactly once at boot (`info_boot_push_task`), and a push that
arrives with no task registered is NACKed and lost.

Because a boot push and a query reply are byte-identical, "nobody asked" is
what identifies a reboot — which is why `InfoClient` owns the inbox with a
single consumer rather than letting callers drain the queue.

* **About → Pin Configuration...** shows the live `GET_PIN_CONFIG` reply drawn
  over `assets/pinout.png`, plus a legend of what each pin does.
* The firmware version appears in the status bar, refreshed on connect and on
  every detected reboot.

## PCF8575 expander task (task 7)

Mostly ordinary write commands, but `READ_PORT` and `SCAN` are queries with the
same request/reply shape as INFO — hence `ExpanderClient`, which owns task 7's
inbox. Two differences from `InfoClient`: nothing is ever pushed unsolicited on
this task, and the replies echo their subcommand in byte0, so they're
self-describing rather than classified structurally.

All eight addresses the part's A2/A1/A0 pins can select (0x20–0x27) are
reachable: **manualCtrl → PCF8575 Expander...** has an address combobox, an
address scan, 16 write-through pin toggles, whole-port and mask operations, and
a read-back row. Note the quasi-bidirectional pin semantics (a pin driven low
always reads back 0) documented in [`../docs/PCF8575.md`](../docs/PCF8575.md).

## Protocol version compatibility

`GET_FW_VERSION` carries `UART_PROTOCOL_VERSION` (see `uart_task_ids.h`) at a
*fixed* byte offset that never moves across versions, so it can always be read
and compared before trusting the rest of the payload. `InfoClient.compatible`
is `None` until a version has actually been observed (query reply or boot
push), `True`/`False` after. Both the GUI and the MCP server refuse to send
any DAC/AD9833/OLED command — blocking on `None` too, not just `False` — until
compatibility is confirmed `True`; INFO queries themselves are always allowed,
since that's how compatibility gets discovered in the first place. The GUI
also pops an error dialog once per connection on a confirmed mismatch and
turns the status-bar FW line red.

There's no automatic way to tell whether an arbitrary firmware change would
actually break the wire format, so `UART_PROTOCOL_VERSION` is a manually
maintained integer (bump policy documented next to it in `uart_task_ids.h`),
not a hash of the header — a hash would flag harmless edits (comments,
reordering) as incompatible just as readily as a real break.

## Connecting does not reset the board

Two things had to be right for this, and both were wrong before:

* `UartLink.connect()` configures DTR/RTS **while the port is still closed**,
  then opens it. Passing `port=` to `serial.Serial()` opens with those lines
  at their driver defaults, which pulses the board's auto-reset circuit —
  deasserting them afterwards is too late.
* The starting `MSG_INDEX` is randomized per connection. The firmware's dedup
  ring outlives any host session, so restarting the host at index 0 made its
  first sends look like retransmits: re-ACKed, never delivered. See
  [`../docs/UART_PROTOCOL.md`](../docs/UART_PROTOCOL.md).

Together these are why the first query after a connect used to fail with
"ACKed but no reply arrived", recovering only when the firmware's
once-per-boot version push happened to land right after.

## Session logs

Both the GUI and the MCP server write one log file per session to
`pc_tools/logs/session_*.log`. A new file starts when a connect succeeds or
when a device reboot is detected — both semantic triggers, hence a
hand-swapped `FileHandler` rather than one of `logging`'s size/time rotating
handlers. **Logs → Keep Logs...** sets how many files to retain (persisted in
`src/uart_control/settings.json`, along with the last-used serial port, which
is preferred over the autodiscovered recommendation the next time a port is
still present); **Logs → Show Log...** is the in-app view.

## Known limitation

`uart_bridge.c` only ACKs/NACKs at the protocol layer for the DAC and AD9833
tasks; it never sends an application-level status frame back. A send result of
`ok` therefore means "delivered to the ESP task's inbox", **not** that the
underlying I2C/SPI device operation succeeded. Device-level failures are only
visible on the ESP's own console log. (Task INFO is the exception: it really
does answer with data.)

## Self-check

```powershell
uv run --project pc_tools python pc_tools/selfcheck.py
```

Runs framing/CRC/payload-layout checks and cross-wires two `UartLink`s over a
fake port — including a stub `info_bridge_task` — so the INFO query flow and
the boot push are exercised without hardware.

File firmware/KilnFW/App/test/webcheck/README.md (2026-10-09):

# Browser checks for the KilnFW web UI

Three checks that catch classes of bug the host tests structurally cannot:
the host suite never renders a page, and `curl` never runs the JavaScript or
opens more than one connection at a time. Every bug listed below was reported
by the owner from a real browser and was invisible to everything else we had.

| Script | Needs a board? | Catches |
|---|---|---|
| `../lint_pages.js` | no | inline-script syntax errors |
| `topbar_check.js` | yes | Home/Menu misalignment on any page |
| `ui_sweep.js` | yes | overflow, overlap, small tap targets, console errors, dead buttons |

## Running them

```sh
# No hardware needed -- run this one on every page edit.
node firmware/KilnFW/App/test/lint_pages.js firmware/KilnFW/App/drivers

# These need a reachable board (override the address if it moved).
node firmware/KilnFW/App/test/webcheck/topbar_check.js
KILN_BASE=http://192.168.1.156 node firmware/KilnFW/App/test/webcheck/ui_sweep.js
```

Playwright is not vendored here. Install it wherever you run these:
`npm i playwright && npx playwright install chromium`.

`lint_pages.js` is also run automatically, no manual invocation needed, by
`tools/check_lint_pages.ps1` as part of the standing `tools/run_all_checks.ps1`
suite, and by `tools/verify.ps1`'s `lint` stage (which delegates to that same
script).

## Why each exists

**`lint_pages.js`** — a comment written as `MAX31856_MASK_*` followed by `/`
closed its own block comment early, so the rest of the line parsed as code.
The syntax error killed the entire inline script, and the thermocouple faults
page sat on "Loading…" forever while its endpoint answered correctly in 160 ms.
`curl` saw a perfect page and a perfect API; only a browser saw the failure.

**`topbar_check.js`** — nav.js injects the topbar into every page, but Home is
an `<a>` and Menu is a `<button>`. Any page-local rule targeting bare `button`
hits one and not the other: `zones_page.html`'s `button { margin-top: 1em; }`
pushed Menu 13.6 px below Home. A second, subtler version survived that fix —
a `<button>` does not inherit the page font, and `line-height: normal` resolves
taller in a button than in a link, leaving the Menu label 3 px low on *every*
page.

**`ui_sweep.js`** — the "Download backup button goes out of frame on the phone"
class of report. Runs each page at phone, tablet and desktop widths.

## Two hard-won cautions

**Close every browser you open, and never run two of these at once.** The
board's HTTP server has a bounded socket pool; abandoned browser connections
wedge it until they are killed, and the symptom looks exactly like a firmware
hang. Killing the stray browsers brings it straight back.

**A clean sweep is weaker evidence than it looks.** These scripts load pages
sequentially, so they rarely open enough concurrent connections to reproduce a
load-dependent failure. A sweep reported "console errors: none" on the very
build whose faults page failed 3-for-3 in a normal browser tab. Treat a clean
run as "nothing obvious", not "verified".

## After flashing, hard-reload first

Assets are served with `Cache-Control: no-cache` as of 2026-08-22, but a
browser that cached them *before* that change can still hold a stale copy.
A page rendering markup the firmware no longer contains is the signature —
check that before debugging the page itself.

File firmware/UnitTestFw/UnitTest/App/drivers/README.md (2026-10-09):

# DcDac Device Driver

This component implements a lightweight MCP4728 driver with support for multiple variants and configurable command formats.

See the project-level documentation for details: `docs/MCP4728.md`.

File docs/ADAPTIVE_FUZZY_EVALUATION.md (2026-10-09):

# Adaptive fuzzy: the evaluation that would decide it (2026-09-14)

**Status: BUILT AND RUN (2026-09-16); outcome recorded in the audits, this plan
is now history.** Built: the `sim_plant.c` delay-ring truncation flag
(`delay_truncated`), `pid_fuzzy_confidence.{c,h}` (`ee55af58`, sec 3's
confidence gate) and the adaptive arms plus sec 7 gates in
`sim_factorial_driver.c`. Outcome, read in order:
`docs/audits/adaptive_fuzzy_section8_campaign_2026-09-16.md` (gate 1 FAIL,
run inert), `adaptive_fuzzy_section8_dwell_fix_2026-09-16.md` (gate 1 still
FAIL, second cause), `adaptive_fuzzy_section8_cell_mix_rebuild_2026-09-16.md`
(**gate 1 PASS, gate 2 PASS, gate 3 FAIL**; integrity PASS). **Owner decision, 2026-10-07 (closes the former
open items):** adaptive fuzzy stays in the code at strength 0; there is no removal and no gate-3 rework
(gate 3 is not amended). It is revisited after real firings, using
`firing_shadow` data. Nothing is open on this plan. (Prior context: gate 3 as
written fires on any limit-cycle crossing and cannot separate a fuzzy-induced
cycle from ordinary adaptive-PID dwell settling; 3 of 7 pinned cells differ from
the control arm, 4 of 7 are identical.) No board was flashed and no heating run was performed.

## 0. Why this document exists

`docs/audits/scenario_factorial_results_2026-09-14.md` (+ the opus review,
`e2245b8d`) established that **fixed-gain** fuzzy at strength 50 is net
harmful: 175 degraded cells vs 128 improved at the 0.5 °C materiality floor
across 263 cells; 91 degraded-only vs 9 improved-only in the 151 bench-span
cells; `ENTRY_PEAK_C` — the feature's own stated purpose — degrades 108 and
improves 53; seven cells show a converged, bounded limit cycle. Four artifact
hypotheses were tested and rejected, and correcting the bench-valued dead time
makes the harm *worse*.

That document says so itself: the suite has **no adaptive arm**, so
`D_adapt`/`D_combo` are not computable and the verdict does not reach the
learning variant the owner has repeatedly said is the intended one. This plan
specifies the run that would.

**The short answer to "is this even distinguishable in simulation?": yes, and
cheaply.** Measured on this machine, the existing 789-firing factorial driver
runs in **2.3 s** (~2.9 ms per simulated firing). The adaptive arms add
263 cells × 2 arms × 9 firings = 4,734 firings ≈ **14 s**. The multi-firing
sequencing is not the constraint, and **no cell needs to be dropped** (§5).

---

## 1. What "adaptive fuzzy" concretely is, in this codebase

Stated as three disjoint lists so the implementer never has to guess which is
which.

### 1.1 Already built and shipped

| Piece | Where | What it does |
|---|---|---|
| Band derivation from the identified plant | `pid_fuzzy_derive_bands()`, `pid_fuzzy.c` (`2c49465a`) | `error_band_c = K_dc * 0.5`, `rate_band_c_per_s = K_dc / tau_s` |
| No model ⇒ no fuzzy | `pid_fuzzy_prepare_gains()`, `profile_executor_pid_tick.c` (`fuzzy_no_model_no_fuzzy_2026-09-14`) | a never-autotuned zone forces `strength_pct = 0`, i.e. bit-for-bit plain PID |
| `K_dc` refinement across firings | `adaptive_tune.c` / `adaptive_tune_model.c` | moves `K_dc`, so the bands move with it |
| Harvest freeze (the "Option B" precondition) | `harvest_freeze` in `profile_executor.c:988` → `strength_pct = 0` during dwell harvest | fuzzy cannot shape the trace the identification fit is taken from |
| A 9-firing adaptive chain harness | `sim_scenarios_adaptive.c` (`SIM_ARM_PID_AT`, `SIM_ARM_FUZZY_AT`, `N_FIRINGS 9`) | real `adaptive_tune.c` against a persistent per-chain zones-config fake, over the 11-scenario table |

So a weak form of adaptive fuzzy **already runs today**. Be precise about how
weak, per `docs/audits/concurrent_fuzzy_pid_adaptation_2026-09-14.md` §5:
both bands scale in the **one** scalar `K_dc`, and their ratio is exactly
`tau_s`, which `adaptive_tune` never moves ("dwell data cannot inform
dynamics"). The *shape* of the fuzzy input plane is frozen at the original
autotune for the life of the zone. Nothing about the rule table,
`MAX_NUDGE_FRACTION` or `fuzzy_strength_pct` adapts at all.

### 1.2 Specified but unbuilt

- **Confidence-graduated authority.**
  `docs/audits/adaptive_tune_confidence_authority_design_2026-09-13.md`
  specifies it, but for `adaptive_tune`'s **own** guards (`BLEND_ALPHA`,
  `MIN_OBSERVATIONS`) — *not* for fuzzy's strength. Its `1142c73b` review
  refuted the non-circularity argument as written and listed required changes
  before it is buildable.
- **The adaptive factorial arms.** `docs/audits/scenario_factorial_design_2026-09-14.md`
  §5.1 already names `D_adapt` and `D_combo` and already costs a 6-arm /
  22-firing-per-cell structure. `sim_factorial_driver.c` implements only
  3 single-firing arms. This is specified-but-unbuilt, not new.

### 1.3 Newly specified here

**(N1) Confidence drives `fuzzy_strength_pct`, from 0 upward.**
`concurrent_fuzzy_pid_adaptation_2026-09-14.md` §5 says adapting
`fuzzy_strength_pct` "should NOT, without Option B". **Option B is now
shipped** (`harvest_freeze`, table above), so that precondition is met — flagged
here rather than silently assumed. The remaining objection in that section is
that scoring *firing outcomes* is closed-loop-heuristic adaptation. This plan
**avoids that objection entirely by not using outcome scores**: confidence is a
property of the **plant identification** (§3), never of how the loop looked.

**(N2) A dead-time authority cap, and (N3) an in-firing oscillation detector.**
These are new and they exist because of a specific finding below.

### 1.4 The finding that shapes this whole design — state it loudly

The seven-cell failure is a **gain-scheduling-induced limit cycle closed
through a large transport delay**, and the review measured it **monotone in
dead time** (0 s → 9.63; 10/20/30 s → 22.2/46.2/64.5; 40.3 s → 84.2; 64 s →
117.8). Every *fixed* gain vector tested was stable, including ones outside
everything fuzzy realises. Only the time-varying schedule oscillates.

**Therefore a confidence gate built on `K_dc` agreement would NOT have
prevented it.** In those cells the model is *correct* — `A6 = MATCHED` — so
`K_dc` confidence would be HIGH and would raise authority into exactly the
regime that limit-cycles. A confidence gate that does not demonstrably prevent
the observed failure mode is not a fix (the task says so, and it is right).
Hence (N2) and (N3), which are aimed at the real mechanism (`L`, and
oscillation itself) rather than at model quality.

---

## 2. Bootstrap from autotune

Owner requirement: fuzzy constants derive from the PID autotune on the
installed kiln, never from fixture constants.

| Fuzzy parameter | Source | Notes |
|---|---|---|
| `error_band_c` | `K_dc * ERROR_BAND_K_FRACTION` | **already shipped**, do not re-derive |
| `rate_band_c_per_s` | `K_dc / tau_s` | **already shipped** |
| `fuzzy_strength_pct` | **0** at bootstrap, rising only under §3 | new; today's default of 50 is what the factorial condemned |
| rule table, `MAX_NUDGE_FRACTION` | compile-time, unchanged | out of scope; `pid_fuzzy.h:17-21` closed per-install rule tables deliberately |

**Before any autotune has ever run:** nothing changes — the shipped no-model
path already forces `strength_pct = 0` and logs once per zone per boot. An
un-autotuned zone runs plain PID. That is correct and needs no new code.

**Consequence worth naming:** with `strength_pct` starting at 0, **firing 1 of
the adaptive arm is bit-for-bit `A_PID`**. The feature's floor is exactly the
control it is compared against, so it cannot be worse than PID before it has
earned anything. This is the same "the floor state IS today's shipped
behaviour" safety argument the confidence design makes in its §4, reused
deliberately.

---

## 3. The confidence gate

### 3.1 What confidence is measured from

Reuse the confidence design's §1 signals verbatim — do not invent a second
definition:

1. **Forward-checked predictive residual.** At run N+1's run-end, before
   folding N+1's observations in, score how well run N's model predicted N+1's
   settled-dwell observations:
   `residual_frac = |K_dc_after_N * duty_obs_N+1 − rise_obs_N+1| / rise_obs_N+1`.
2. **Fit stability.** Coefficient of variation of the last K accepted raw
   `K_fit` values narrowing rather than wandering.
3. **Eligibility gate, not an input:** the existing
   `ADAPTIVE_TUNE_MIN_DUTY_SPREAD` must have been satisfied over the runs being
   scored.

Carry the `1142c73b` review's caveat forward rather than waving it off:
cross-run ring contamination makes the residual **partly in-sample**, and
selection bias is the real leak. That review's required changes are a
prerequisite for shipping this on hardware. **They are not a prerequisite for
the simulation run**, because in simulation the true plant is known and the
implementer must additionally log the *true* `K_dc` alongside the estimate, so
the residual's optimism is measurable rather than argued.

### 3.2 The authority schedule

```
c        = consecutive runs with both signals inside band, clamped to [0,4]
cap_L    = 1.0 if (L/tau) <= 0.10
           linear 1.0 -> 0.0 over 0.10 < (L/tau) <= 0.30
           0.0 if (L/tau) > 0.30                       <-- (N2)
strength = round( S_MAX * (c/4) * cap_L )              S_MAX = 50
```

- `c = 0 ⇒ strength 0 ⇒ plain PID.` **That is the answer to "what happens when
  confidence is LOW": the feature is off, bit-for-bit.** There is no
  low-confidence mode with reduced-but-nonzero authority to reason about.
- Rise is rate-limited to one step per accepted run; fall is immediate to the
  floor on any disqualifier (confidence design §5's deliberate asymmetry).
- **`cap_L` (N2)** is the anti-limit-cycle term. `L` and `tau` are autotune
  outputs already on the board, so it is bootstrap-time computable and needs no
  new measurement. The 0.10/0.30 breakpoints are **chosen, not measured** —
  label them as such. The factorial run is precisely the instrument that tests
  whether they are placed correctly: the seven known cells sit at
  `L/tau = 40.3/488 = 0.083` at the bench value but at `76.9/488 = 0.158` once
  kiln-scaled (§6), i.e. **inside the taper**, which is the intended behaviour
  and is a falsifiable claim about the breakpoints.
- **Oscillation detector (N3).** Within a firing, count error zero-crossings
  over a rolling window during a dwell. The measured contrast is stark — 29
  crossings in the oscillating arm, **0** in both stable arms — so the
  threshold has enormous margin. On trip: `strength_pct → 0` for the remainder
  of the firing, and confidence → floor at run end. This is an outcome-derived
  signal, so per §1.3 it is deliberately allowed to **only ever reduce**
  authority, never raise it — that direction carries none of the
  closed-loop-heuristic hazard.

---

## 4. Known traps, and how this design avoids each

| Trap | Avoidance |
|---|---|
| **The `DT_S` trap.** Sweeping the controller timestep collapses the oscillation (84.2 → 9.9) and looks exactly like proof of a numerical artifact. It is not — it only shortens the effective dead time via the 63-step ring clamp. | **Do not sweep `DT_S`.** 1 Hz is the production tick (`PROFILE_EXECUTOR_TICK_MS 1000`) and is correct. Refine the *plant ODE* sub-steps instead if convergence must be re-checked; that was done and moves the result 3.5 % at 64×. And §6 makes the silent clamp loud, which removes the trap at its source. |
| Simulator feeds `sim_kiln_step()` the **binary** relay state, not fractional duty. | The factorial driver's single-zone path uses `sim_plant_three_node_step()` with continuous duty and is not affected. **If any multi-zone cell is ever added, window-average duty before feeding duty-nonlinear plant terms.** No multi-zone cell is in this design. |
| The firmware's coupling model class (`G*u = b`, additive duty-driven off-diagonals) is **refuted on hardware** — superposition fails by 33 %. | This design is **single-zone throughout** and makes no superposition claim. Sensitivity: the whole result is conditional on single-zone dynamics; on a real multi-zone kiln, cross-zone duty will perturb each zone's identification and therefore its confidence. **That is untested and must be stated in any conclusion drawn from this run.** |
| Fuzzy was previously A/B tested **inert** because the control mode was wrong (mode 2 made two whole campaigns meaningless). | §7's activity proof: instrumented per row, asserted mechanically, non-zero exit if inert. Never assumed. |
| A harness that prints a verdict and exits 0 (`sim_iter_tune`'s printf-only accept bars). | §7's failure signal: every gate returns a non-zero process exit. |
| The bench is a ~4 W / 120 V fixture that cannot exceed ~40 °C above ambient. | Every kiln-span number in this plan and in its output must be labelled **[EXTRAPOLATION]**. The 112 kiln-span cells are extrapolation beyond any hardware this project has; the 151 bench-span cells are the only regime with corroboration. Reported separately, always. |

---

## 5. How the factorial arm is added

### 5.1 Structure

- **Two new arms**, reusing the names that already exist in
  `sim_scenario_table.h`: `A_PID_AT` (adaptive PID, fuzzy off) and
  `A_FUZZY_AT` (adaptive PID + confidence-gated fuzzy).
- **Each cell runs a chain of N = 9 sequential firings**, adaptation state
  (model, gains, `autotune_baseline_k_dc`, confidence counter) carried across
  them. **N = 9 is not a new number** — it is `sim_scenarios_adaptive.c`'s
  existing `N_FIRINGS`, kept so the two harnesses stay comparable. The existing
  three arms stay single-firing.
- **Implementation route: extend `sim_factorial_driver.c`'s arm enum and lift
  `sim_scenarios_adaptive.c`'s chain mechanics** (its zones-config fake, its
  run-end wiring, its per-firing print) rather than writing a third copy of the
  tick loop. The driver's header already warns that it is a near-duplicate of
  `sim_scenarios.c`'s `run_firing()`; **do not create a fourth**. If the heavier
  link surface (`adaptive_tune.c` pulls `hal_kv`/`esp_log`/`flash_worker`/a
  FreeRTOS mutex shim) makes one executable unwieldy, build a **second**
  executable over the same cell list — that is exactly the reasoning
  `sim_scenarios_adaptive.c` already documents for its own split.

### 5.2 Cost, measured not guessed

| | firings | measured cost |
|---|---|---|
| existing 3 arms × 263 cells | 789 | **2.3 s** (measured, this machine, `--of 1`, `-SkipDeterminism`) |
| new 2 arms × 9 firings × 263 cells | 4,734 | ~14 s at the same 2.9 ms/firing |

Even allowing 3× for `adaptive_tune`'s per-run-end work and the kiln cells'
longer ramps, this is **under a minute single-process** and seconds sharded
four ways. **No factor is dropped and no cell is dropped.** The suite stays a
manually-invoked `--suite factorial` target; **do not raise
`check_sim_scenarios.ps1`'s 60 s CI budget** — the 13 named anchors stay there.

### 5.3 What does NOT need to change

The design generator (`sim_factorial_design.c`, 224/39/263 and the single
feasibility mask) is untouched. Sharding stays cell-index modulo; a chain is
entirely within one cell, so shard-independence survives and
`run_sim_factorial.ps1`'s `--of 1` vs `--of 4` byte-identity proof must still
pass (with `-SkipDeterminism` **not** set for the recorded run).

---

## 6. Kiln-scaled parameters

The fixed run held sensor-node tau and dead time at bench values even for
kiln-span cells. The review showed this **under-states** harm, so it was not
fatal there — but it is physically inconsistent and is corrected here.

| Fixture | Bench cells | Kiln-span cells (`A4 = 20.7`) |
|---|---|---|
| `sensor_delay_s` | 40.3 s (unchanged) | **76.9 s** (40.3 × 488/255.6) |
| `sensor_tau_s` | 15 s (unchanged) | **28.6 s** (15 × 488/255.6) |
| `c_s_j_per_c` | 500 | 500 — **provably inert**, a 10× change is bit-identical (only `c_s/sensor_tau_s` enters `dS`, and it cancels). Strike it from the assumptions list. |

### 6.1 The 63-step ring, and the required harness change

`sensor_pipeline_step()` (`sim_plant.c:51`) clamps `delay_steps` to
`SIM_PLANT_DELAY_MAX_STEPS − 1 = 63` **silently**. At `dt = 1` the kiln-scaled
76.9 s therefore becomes 64 s — detected originally because the 76.9 s and
64.0 s rows came out byte-identical.

Two changes, both in test-fixture code only:

1. **Raise `SIM_PLANT_DELAY_MAX_STEPS` from 64 to 128** (`sim_plant.h:24`). It
   is a `float` ring in a host-test struct; the cost is 256 bytes per zone.
2. **Make the clamp loud.** `sensor_pipeline_step()` must set a
   `delay_truncated` flag on the state when the requested delay exceeds
   capacity, and every driver must **refuse the cell** on that flag rather than
   silently proceed. This is the actual fix for the `DT_S` trap: after it,
   anyone shrinking `dt` gets a refusal instead of a quietly shortened dead
   time and a wrong "artifact" conclusion.

**Mandatory regression proof:** bench-span cells use 40.3 s < 63 steps, so they
must be **bit-identical** before and after. Re-run the existing 3-arm sweep and
diff the 151 bench-span cells' rows byte-for-byte. If they differ, the ring
change did something unintended — stop and investigate before proceeding.

---

## 7. Proving the adaptive arm is actually active

Registered before the run, because this project has already lost two whole
campaigns to an inert arm.

Per (cell, arm, firing) row, emit: `strength_pct_realised_mean`,
`strength_pct_realised_max`, `ticks_with_strength_gt_0`, `confidence_c`,
`cap_L`, `error_band_c`, `rate_band_c_per_s`, `model_k_dc`, `true_k_dc`,
`oscillation_tripped`.

Three mechanical gates, **each a non-zero process exit**, never a printed
verdict:

1. **Activity gate.** `A_FUZZY_AT` must reach `strength_pct > 0` for at least
   one tick in **≥ 30 %** of cells by firing 9, and `A_FUZZY_AT` firing 9 must
   differ from `A_PID_AT` firing 9 by more than the 0.5 °C floor on at least
   one objective in **≥ 10 %** of cells. Below either ⇒ FAIL: the arm is inert
   and the run is uninterpretable, exactly as in the mode-2 campaigns.
2. **Floor-identity gate.** `A_FUZZY_AT` firing 1 must be **bit-identical** to
   `A_PID_AT` firing 1 on every cell (§2's consequence). A difference means
   strength was non-zero before confidence was earned.
3. **Limit-cycle regression gate.** The seven known cells — `ST1-049`,
   `ST1-057`, `ST1-113`, `ST1-121`, `ST1-177`, `ST1-241`, `ST1-249` — are a
   pinned fixture. In `A_FUZZY_AT`, **zero** dwell error zero-crossings in any
   of the nine firings. Any crossing ⇒ FAIL.

Also required, and separately fatal: any cell refusal, any NaN, any delay-ring
truncation flag, and any `--of 1` vs `--of 4` mismatch.

---

## 8. The comparison that decides the feature — registered before any data exists

**Decision rule (the owner's, unchanged): count cells improved vs degraded
past a 0.5 °C materiality floor. Harmful more often than helpful ⇒ REMOVE.**

**Primary comparison, fixed now:**

```
D_adapt_combo = obj(A_FUZZY_AT, firing 9) - obj(A_PID_AT, firing 9)
```

i.e. **the adaptive-PID arm is the control**, not plain PID. That is literally
the before/after of deleting adaptive fuzzy from a board that will have
adaptive PID either way.

**Counting unit: PER CELL, not per (cell, objective) pair. Fixed now, before
any data exists.** Reason, stated in advance so it cannot be chosen after the
fact: **fuzzy is enabled per plant, not per objective** — a zone either runs it
or does not. A cell counts as improved if it improves on ≥ 1 of the four
objectives and degrades on none; degraded if it degrades on ≥ 1 and improves on
none; mixed cells count toward **both** improved and degraded totals, exactly as
the fixed run reported them (175 / 128).

The fixed run's per-pair count **inverted** the verdict (286 vs 233), driven
entirely by kiln-span cells. Per-pair will still be reported — as a **declared
secondary**, labelled as the inverting slice — so the reader sees the same
tension the fixed verdict disclosed. It does not decide anything.

**Pre-registered subgroup reporting** (all three, always, no post-hoc choosing):

- All 263 cells — the headline.
- **151 bench-span cells** — the only regime with hardware corroboration; this
  is the subgroup to believe if the two disagree.
- **112 kiln-span cells — [EXTRAPOLATION]**, far beyond a ~4 W fixture, with a
  load node that never approaches setpoint.

**Secondary comparisons, reported but not decisive:**

- `D_adapt = obj(A_PID_AT, firing 9) − obj(A_PID, firing 1)` — does adaptation
  alone help? Needed to tell "adaptive fuzzy helped" from "adaptation helped".
- `D_learn = obj(A_FUZZY_AT, firing 9) − obj(A_FUZZY_AT, firing 1)` — did it
  learn anything at all across the chain?
- `D_fixed_vs_adaptive = obj(A_FUZZY_AT, firing 9) − obj(A_FUZZY50)` — is the
  adaptive variant better than the condemned fixed one?

---

## 9. Falsifiable prediction, registered in advance

**Removal criteria — any one of these ⇒ REMOVE adaptive fuzzy:**

1. **Net harm.** In `D_adapt_combo`, per cell, over all 263 cells, degraded ≥
   improved. (The fixed arm scored 175/128 — a failure.)
2. **Bench-span harm.** In the 151 bench-span cells, degraded-only ≥
   improved-only. (Fixed scored 91/9.)
3. **Purpose failure.** On `ENTRY_PEAK_C` alone, degraded > improved. Fuzzy
   exists to cut overshoot; failing that is disqualifying regardless of the
   other three objectives. (Fixed scored 108/53.)
4. **Gate failure.** Any of the seven pinned cells still limit-cycles (§7 gate
   3). **This one is independent of every tally** — a confidence gate that does
   not prevent the observed failure mode is not a fix, so this removes the
   feature even if criteria 1–3 all pass.

**My prediction, written before the run.** The gate (§7 gate 3) holds — the
mechanism (`cap_L`, then the crossing detector as backstop) is aimed directly
at the measured driver, so I expect zero limit cycles. On the tallies I expect
**near-neutrality with a large within-floor mass**, specifically: within-floor
on all four objectives in **> 120** of 263 cells, improved > degraded but by a
margin **under 40 cells**, and `D_learn` material in **< 25 %** of cells.

That prediction is itself an argument against the feature and is stated as
such: if adaptive fuzzy survives its removal criteria only by being *inert
almost everywhere*, the honest reading is that it passes because it does
nothing, not because it works. **Register the follow-on rule now:** if
criteria 1–4 all pass AND the improved-minus-degraded margin is under 20 cells
AND within-floor exceeds 150, report the result as **"survives, but
indistinguishable from plain adaptive PID"** and put the keep/remove decision
back to the owner rather than claiming a win.

---

## 10. Honest limits

- Everything here is **simulation**. A sim win is screening, not evidence of
  hardware improvement — this project's standing position, and it is not
  relaxed by adding an arm.
- Single-zone only. The refuted coupling model means nothing here transfers to
  multi-zone behaviour (§4).
- The confidence residual is partly in-sample (`1142c73b`). The sim knows the
  true `K_dc`, so the optimism is *measurable* here; on hardware it is not, and
  that review's required changes remain a shipping prerequisite.
- `cap_L`'s breakpoints (0.10 / 0.30) are chosen by desk reasoning. The run
  tests them; it does not derive them.
- Every kiln-span number is **[EXTRAPOLATION]** from a ~4 W fixture.
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

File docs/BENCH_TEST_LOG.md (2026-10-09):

# Bench Test Log

One line per `bench_test_run()` call, newest last, appended automatically
by `report.append_log_line()` (plan §7 owner decision 1: gitignored
`logs/bench_test/<run>/` for the full machine record, plus a human sentence
here). Never edit a past line by hand -- append only. A line never carries a
credential; anything that looks like one is `***` before it is written, same
as `transcript.md`/`summary.json` (`_redact()`).

- `20260921T004103Z_smoke` suite=`smoke` exit_code=2 PASS=0 FAIL=0 INCONCLUSIVE=0 NOT_RUN=36 SKIP=0 esp_fw=unknown pico_fw=error: SafetyQueryError: SAFETY request 0x0B not delivered: no serial port open - connect first log=`logs/bench_test/20260921T004103Z_smoke/`
- `20260921T004457Z_smoke` suite=`smoke` exit_code=1 PASS=6 FAIL=27 INCONCLUSIVE=2 NOT_RUN=1 SKIP=0 esp_fw=Sep 20 2026 17:38:28 pico_fw=error: SafetyQueryError: SAFETY request 0x0B not delivered: no serial port open - connect first log=`logs/bench_test/20260921T004457Z_smoke/`
- `20260921T010207Z_smoke` suite=`smoke` exit_code=1 PASS=8 FAIL=24 INCONCLUSIVE=3 NOT_RUN=1 SKIP=0 esp_fw=Sep 20 2026 17:38:28 pico_fw=error: SafetyQueryError: SAFETY request 0x0B not delivered: no serial port open - connect first log=`logs/bench_test/20260921T010207Z_smoke/`
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

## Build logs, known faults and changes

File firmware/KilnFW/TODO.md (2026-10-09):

# TODO — Web UI / Kiln Control Front End

Top-level ordering across both processors lives in [`../../ROADMAP.md`](../../ROADMAP.md);
this file owns the main-firmware detail. The cross-processor items — the swapped
safety-UART pins, `CommonFW`, and the safety-liveness gate on heating — are
sequenced there and tracked in [`../SaftyFW/TODO.md`](../SaftyFW/TODO.md).

## Bench sweep 2026-08-27 -- running profiles and autotunes, no heaters

Heaters disconnected, thermocouples connected and reading ambient. A firing
and an autotune run back to back on zone 0 -- the sequence an operator
investigating a bad element would perform. Fixed and committed from this
round: the all-OFF profile that ran silently, the PC-link watchdog opening
relays a firing owned, the guard-trip latch that disabled a zone permanently,
autotune blaming the kiln for its own inaction, and the missing
heat_block_sources / zone_blocked_mask reporting.

What behaved correctly and is now known-good on hardware: the bang-bang
control loop (relay closed at the 2 C hysteresis crossing and held for
minutes); thermal guard 1, which tripped at 296 s of commanded heat with
"heating but rose only -0.0C in 5.0min (need >=25.0C)", dropped the relay and
aborted the run; and autotune's fit, which refused to produce a model from a
flat trace instead of proposing gains from a zero-gain plant.

Still open from this round:

- [x] **`guard_wrong_dir_window_s` does not control the guard an operator
      would think it does.** DONE 2026-08-26: the field now feeds both
      branches, and guard 1 additionally gained its own
      `guard_progress_window_s` (and `guard_progress_duty_min`) on
      /settings/safety, so the heating-failed case is configurable in its own
      right rather than borrowing guard 2's field. Bench-confirmed: a dead
      element tripped at 64 s against a configured 60 s window, where it
      previously took the hardcoded 300 s. The per-zone field is exposed in Settings > Zones
      and reads as "how long heat may be commanded without a response", but it
      only feeds guard 2 (already at/above setpoint and falling). The
      heating-failed case -- the one that matters when an element dies -- uses
      the hardcoded `PROGRESS_WINDOW_S` (300 s) and cannot be configured at
      all. Either wire the field to both or rename it.
- [x] **The frozen-sensor guard cannot fire on real hardware.** DONE
      2026-08-26: `FROZEN_EPS_C` (0.05 C) epsilon band added, and exposed as
      the per-zone `guard_frozen_eps_c` override on /settings/safety. It resets its
      window on any change at all (`in->measurement_c != state->frozen_last_c`),
      and a live MAX31856 dithers by 0.01-0.1 C every read, so the 120 s window
      never accumulates. It can only catch a bit-exact frozen value. Needs an
      epsilon band.
- [x] **Autotune's relay switching is not counted toward contact wear.**
      DONE 2026-08-26; bench-confirmed, the counter moved 9 -> 27 across one
      step test.
      `relay_cycles` is fed only by profile_executor's accounting, so a long
      relay-feedback autotune ages the contacts invisibly.
- [x] **A completed or faulted run never releases its relay ownership**
      DONE 2026-08-26 -- `release_profile_relay_claim()` on every path leaving
      RUNNING; bench-confirmed by a manual relay command succeeding after a
      faulted run.
      (already tracked below) -- confirmed live this round: relay 1 stays
      RELAY_OWNER_PROFILE after the run ends.

---

## Bench sweep 2026-08-27 -- exercising the LCD and web interfaces

Every HTTP endpoint fetched and strict-parsed, every mutating endpoint
exercised against the live board (47 checks, heaters powered down), and the
LCD walked page by page with injected touches. Fixed and committed from this
sweep: `/api/status` emitting bare `nan`, danger mode leaving relays closed
on exit, the tap-target dump captioning containers with a hidden child's
text, and the safety-link config-page hardening. Still open:

- [x] **Page 1 of a two-page safety config is never received.** This note
      predates the actual root cause, found the next day: `3149393` (2026-08-28)
      -- the ESP's `uart_protocol_rx_task` read UART bytes 32 at a time, so a
      ~157-253 byte CONFIG_PAGE took 5-8 scheduler round trips to assemble
      against the reply window, while small STATUS/DIAG/POWER frames always
      finished it in 1-2; page 1 (the bigger page) missed its window almost
      every time and page 0 only "succeeded" via stash-adoption. Fixed by
      reading a whole frame in one go (chunk buffer 32 -> `STUFFED_FRAME_MAX`)
      plus 300 ms of fixed reply margin -- not a bigger multi-page ceiling,
      which is exactly what caused the panic-reboot regression named in
      `safety_cfg_store.c`'s own history (see `SAFETY_CFG_STORE_REFETCH_BUDGET_MS`
      and `safety_cfg_store_refetch_nonblocking()`'s comments). Verified live
      then (`cached_config_crc == live_config_crc == 31328`) and re-confirmed
      2026-09-04: `GET /api/safety/commissioning` reads `config CRC 42736
      (matches live, not stale)` and `safety_get_link_stats` shows
      `config_page=0` in the cmd histogram -- i.e. no refetch is even running
      right now because the cache is already converged, which is the designed
      steady state (`safety_cfg_store_maybe_refetch()`: "no UART traffic at
      all, by design"). No analyser capture was ever needed; the Pico was
      innocent, as suspected.
- [x] **The PC-link watchdog drops all relays every 5 s of host silence** --
      confirmed 2026-09-07 that this does NOT abort a running firing: the
      2026-08-27 owner-qualification fix (uart_bridge.c's link_watchdog_task)
      already excludes any relay claimed PROFILE/RULE/AUTOTUNE via
      relay_authority_manual_blocked_by_owner() -- an idle host only expires
      relays it (or a manual UI command) left NONE/MANUAL-owned. Pulled the
      decision logic out into `bridge/link_watchdog_decide.{c,h}` (mirrors
      `profile_executor_wd_decide()`'s split) so it is host-tested against the
      REAL relay_authority.c: `test_link_watchdog.c` proves a PROFILE- or
      AUTOTUNE-owned relay stays out of the watchdog's mask, a MANUAL/NONE-
      owned one stays in it, danger mode zeroes the mask, and traffic resets
      the liveness timer. No behavior change; this closes the "check what
      this does to a running firing" ask with an automated proof instead of a
      one-off bench observation. (`dac91b32`)
- [x] **`max_temp_c == 0` and `max_ramp_c_per_hr == 0` mean opposite things**
      on the same uncommissioned zone -- reconciled 2026-09-06 (see
      `docs/PROFILES.md` "Zero-commissioning semantics"). Rule: both mean
      "not commissioned, refuse to start a firing/autotune" on any zone that
      can heat (`profile_executor_run()`'s existing guard-5/ramp-ceiling
      refusals, `autotune_engine.c`'s prestart checks); everywhere else that
      reads them mid-run treats 0 as "no extra limit", since the start-time
      refusal already made that state unreachable in a real firing. The one
      consumer out of step with this rule, `GET /api/readiness`'s "Guard
      limits (max_temp_c)" item, reported a heating zone's `max_temp_c == 0`
      as ok/deliberately_off instead of not_done -- fixed in
      `readiness_http.h`'s new `readiness_guard_max_temp_status()`, tested in
      `test_readiness_commissioning.c`. `max_simultaneous_relays == 0` is a
      different field (board-wide load-staggering cap, not a per-zone
      commissioning gate) and correctly keeps its "0 = unlimited" meaning
      unchanged -- no inconsistency there. (`1fc9b1dd`)
- [x] **The LCD numbered relays from 1 and zones from 0 on the same page** --
      fixed 2026-08-30 (`UI_PLAN.md` 5.2 audit): `ui_page_temperature.c`'s
      relay tiles, relay error toasts and zone rows are now all 0-based,
      matching the web side's R0-R3.
- [x] **The Safety Processor LCD page never shows the current state.** FIXED
      2026-09-07 -- Diagnostics' Safety & Board Health page (`ui_page_diagnostics.c`)
      now shows live link UP/DOWN (`ds.safety_ready`, the staleness-gated bit,
      not the sticky `link_version_known`), the live ARMED/TRIPPED word (with
      trip reason inline when tripped, already present), and a Commissioned
      Yes/No/unknown row (`ds.safety_build_known` + `ds.safety_config_crc`).
      No new link frames or protocol fields; the Enclosure temp row was
      dropped to hold the page at 5 text rows + 3 cold-junction rows, same as
      before, so the existing no-scroll budget proof still holds.
- [x] **Unknown `/api/*` paths serve the 90 kB dashboard HTML with 200** rather
      than 404 (the catch-all handler). A client gets a page where it expects
      JSON and has to guess. DONE -- `captive_portal_404_handler()`
      (`wifi_provision_http.c:696-713`) exempts the `/api/` prefix from the
      captive-portal redirect and answers it with a real 404 + JSON error
      body instead; only non-`/api/` paths still get the 302-to-dashboard
      redirect.
- [x] **`Accept-Encoding: identity` gets a 406 for every page.** DONE
      2026-09-06 -- documented rather than reworked (storing an uncompressed
      fallback was rejected on the flash budget): `docs/ARCHITECTURE_DECISIONS.md`
      "Web server / transport" now names the behavior and the fix for a
      plain client (`urllib`, some `curl` invocations) -- send
      `Accept-Encoding: gzip` explicitly, or `curl --compressed`.
- [x] **Internal-DRAM regression: superseded.** Re-baselined (`af17e3d`,
      `f426ec6`); `dram_margin.h`'s known-good figures are now largest=18432,
      free=46083 at `app_main_done`, with no regression logged on boot.

---

## 2026-08-28 -- the bench changed, and a batch of owner requests

**THE HEATING ELEMENTS ARE NOW PHYSICALLY CONNECTED.** Every note in this file
that reasons from "relays may be activated but nothing will get warm" is now
false. Read anything about relay behaviour with that in mind.

- The test fixture is capped at **80 C**, enforced today by `max_temp_c = 80`
  on all three zones, set live over `/api/zones`. **This is a fixture
  threshold, not a kiln limit** -- it must come out before a real kiln, and it
  is a concrete instance of `SaftyFW/TODO.md` phase 9's "confirm no test
  threshold was left in place".
- **CORRECTED 2026-09-04, verified read-only against the live board
  (`GET /api/safety/commissioning`):** the safety processor's `abs_max_temp_c`
  no longer reads 0. It is now `{"set":true,"value":80}`, `commissioned:true`,
  config CRC not stale. Something (this pass did not trace exactly what --
  most likely the commissioning-gate interlock, `GUARD_TEST_MATRIX.md` §8)
  has since commissioned it. S1 is therefore now ARMED: `safety_guards.c`
  (`SAFETY_TRIP_OVERTEMP`, gated on `cfg->abs_max_temp_c > 0.0f`) will trip
  and de-energize K4 independently of the ESP on the 3rd consecutive reading
  above `abs_max_temp_c` (the firing-time `min(abs_max_temp_c, firing_max_c +
  firing_margin_c)` tightening was retired 2026-09-24). That ceiling
  (80C) currently equals, not undercuts, the ESP-side zones' own
  `max_temp_c` (also 80) -- real independent backstop, but not a tighter
  second line of defense. See `docs/SAFETY_CASE.md` §2 (H1 row) and §3.1 for
  the full verification and an OWNER-DECISION recommendation to commission a
  tighter value (~70C) given this rig has never fired above 60C --
  superseded by the 2026-09-24 owner decision that the Pico's limits must
  equal the ESP's, never be tighter. The
  original note below is preserved for history; it no longer describes the
  live board.
  <details><summary>Original 2026-08-28 note (superseded)</summary>
  The safety processor was NOT enforcing it. Its `abs_max_temp_c` read
  `set: true, value: 0`, and 0 there means never trip -- so the only ceiling in
  force ran on the same processor that commands the heat. `/api/readiness`
  reporting "all 58 safety parameters have values" is what hid this: it counted
  a zero as a value, while `commissioned` right beside it said `false`.
  </details>
- Relay 4 is currently held closed by rule `R0 (TEMP zone0 >= 25)`, a leftover
  bench rule whose condition is satisfied at ambient. Deleting the rules engine
  (below) will open it.

### Owner requests, 2026-08-28

Done: manual relay page removed (and `POST /api/relay` with it -- the page was
its only caller); board health and thermocouple faults folded into
`/diagnostics` and their routes deleted; safety pages became an expanding nav
group; firing profiles moved to the top of the menu; shared **safety timing
profiles** landed (`ZONES_CFG_VERSION` 8->9, lossless, de-duplicating).

Open:

- [x] **Relay/IO segments in firing profiles**, blocking or non-blocking, each
      segment choosing whether its relay is left in its last state at run end
      (default off). `PROFILE_VERSION` 2->3. DONE -- `PROFILE_SEG_KIND_RELAY_IO`
      (`persist/profiles_types.h`: `io_blocking`, `io_leave_on_at_end`) already
      implements this verbatim; on/off zones (docs/ON_OFF_ZONE_PLAN.md) are a
      distinct, later feature and explicitly say so in that plan's own intro.
- [x] **Delete the rules engine** afterwards, never before -- otherwise there
      is a window with no way to drive a non-zone relay. `rules_task`'s own
      watchdog force-releases and force-offs its relays on a stale tick; that
      protection must be replaced, not merely deleted. DONE -- `rules_task.c`
      no longer exists in the tree.
- [x] **Names for relays not assigned to a zone.** DONE -- `relay_names_cfg_t`
      (`zones_config_accessors.c`/`.h`, `zones_config_get_relay_name`/
      `zones_config_set_relay_name`) already persists a name per relay
      regardless of zone assignment, in its own NVS-backed blob keyed by
      relay number, not zone; exposed dense over `relay_names`/`relay_types`
      in the zones GET/POST HTTP API (`zones_http_get.c`/`zones_http_post.c`),
      editable on `zones_page.html`'s per-relay name/device-type inputs for
      any relay no zone currently claims (`renderRelayNames()`), and shown on
      the LCD temperature page (`ui_page_temperature.c`) in place of the
      zone-owned label. Covered by `test_relay_names_cfg_fs.c`.
- [x] **LCD**: no manual toggling of zone-assigned relays on the temperature
      page (visible, not hidden); safety-processor / board-health /
      thermocouple-fault pages folded into LCD diagnostics and removed; kiln
      setup, thermocouple types and kiln config pages removed; profiles to the
      top-left of the main menu, whole menu on one page. DONE -- verified
      2026-09-20 against the tree: `ui_page_temperature.c` already lists every
      physical relay once, disables (`LV_STATE_DISABLED`, re-checked again in
      `relay_toggle_cb()`) whichever ones `relay_is_zone_owned()` claims for a
      zone while leaving their live state visible, and drives every write
      through `dashboard_set_relay()` (same manual-block/safety-fault gating
      as the web dashboard's own manual relay control) -- see that file's
      header comment. `ui_page_board_health.c`, `ui_page_safety.c`,
      `ui_page_thermo_faults.c`, `ui_page_tc_types.c`, `ui_page_kiln_setup.c`,
      `ui_page_kiln_cfg_setup.c` and `ui_page_zones.c` no longer exist in the
      tree and are not registered in `kiln_ui.c`. `ui_page_config.c`'s nav
      grid builds "Profiles" as its first (top-left) cell, one page, no
      scrolling.

### Two constraints that now bind everything here

**Bytes.** `zones_cfg_t` is 500 of a hard 512
(`ZONES_CONFIG_BLOB_MAX_SIZE`, which also sizes `kiln_cfg_store.c`'s buffer).
The timing-profile work spent the slack getting there -- it reordered
`zone_cfg_t` to kill alignment padding and cut the profile name to 7
characters. Anything new that wants to persist per-zone or per-relay state must
find bytes or take its own NVS key.

**Arrays by value.** `zones_cfg_t.zones[]` and `profile_t.segments[]` are
embedded arrays, so one new field in an element displaces every element after
the first. Every migration needs a FROZEN snapshot struct of the old layout and
a field-by-field walk. `profiles_http.c` already shipped the version that
returns `sizeof` the *current* struct for the *old* version: it rejected every
profile on the owner's board and marked them unused, and only a hardware flash
caught it.

---

## Audit 2026-08-27 -- open items

A six-agent read-only audit of both firmwares. Already fixed and committed: a
stack overflow in `safety_parse_fw_version()`, the unknown-peer-version
fail-open, the trip-event dedup desync, the factory-reset interlock, the
gitignored OTA-rollback setting, and the zones-page error conflation.
Everything below is **confirmed by code reading and still open**, ordered by
severity.

- [x] **A v3/v4 zones blob is adopted as garbage and marked valid.** DONE
      2026-08-26 (commit 03a3424), exactly as prescribed below. All six
      historical layouts were recovered from this file's own git history
      rather than guessed, so every version 1-6 got a real typed converter.
      The mid-struct insertion was v5's `tc_type`, ahead of `model_k_dc` and
      `thermo_mask`. `nvs_load_from()` and `zones_config_import_blob()` now
      share one decoder -- they had each carried a copy of the same bug.
      Bench-verified: the live blob upconverted with every field identical.
      **The `profiles_http.c` sibling immediately below is still open.**
      `zones_http.c`'s older-version NVS load path does **no length check** and
      never calls `validate_zones_cfg()`, and the migration assumes the struct
      only ever grew at the tail -- false, since three of four bumps added
      fields to `zone_cfg_t`, which is an *array element*, so `zones[1]` and
      `zones[2]` are displaced. `tc_type` was also inserted mid-struct.
      Result: `relay_mask`, `max_temp_c` and all eight guard thresholds on
      zones 1-2 become reinterpreted float garbage with the config flagged
      trustworthy. **This is the owner's "did a partial config from an
      incompatible firmware load?" question, and the answer is yes.** Fix: a
      per-version expected-length table checked before anything is touched;
      typed per-version structs with explicit field-by-field upconversion
      instead of memcpy-and-patch; run `validate_zones_cfg()` on this path too
      and clear the valid flag rather than partially defaulting; add a CRC.
      Note the snapshot-restore path has the same memcpy defect but *does*
      validate afterwards, which is why it usually rejects -- same bug, one has
      a net.
- [x] **`profiles_http.c` accepts `version == 0`** DONE 2026-08-27
      (`ee38e39`), built to zones_http.c's design and closed BEFORE
      PROFILE_VERSION reached 2, as this item asked. Note the near-miss: the
      first version of the fix returned `sizeof(the current struct)` for
      version 1, which rejected every profile the bench board already had and
      marked them unused -- it reproduced the data loss it was written to
      prevent, and only a hardware flash caught it. profiles_http.c now has
      its own host-test executable (the seventh) so that case is a permanent
      regression test rather than a scratch harness. at any length >= 1 and
      installs it as a used slot. Same structural sibling waiting to happen:
      `profile_t` embeds a `segments[]` array, so the first field ever added to
      `profile_segment_t` reproduces the zones bug exactly. Fix before
      `PROFILE_VERSION` reaches 2.
- [x] **`POST /api/factory_reset` is still unauthenticated.** DONE
      2026-08-27 (`f58e040`), as prescribed: `ota_http_authenticate_request()`
      exported from `ota_http.c` (the private-header-parsing gap this item
      named), a new `OTA_HTTP_CONTEXT_FACTORY_RESET` with its own lockout
      budget, and auth ahead of the interlock so a refusal reason naming a
      live zone temperature cannot leak to an unauthenticated caller.
      Bench-verified: no header -> 400, bogus MAC -> 403, config intact. The interlock
      landed; auth did not. It is strictly more destructive than
      `POST /api/ota/esp/rollback`, which *is* challenge-response
      authenticated. Needs a new `ota_http_context_t` plus an exported
      request-verify helper (the header parsing is currently private to
      `ota_http.c`).
- [x] **An open AP (empty AP password) reduces OTA auth to nothing.** DONE
      2026-08-27 (`f58e040`) -- refused after the BOOT-button check and
      before any HMAC math, and surfaced as `ota_auth_disabled` on
      `/api/status` next to `boot_button_bypass_active`. The physical
      BOOT-button recovery window is untouched, so an open-AP board is not
      left unflashable.
      `ota_http.c` HMACs with a zero-length key and does not reject it, so
      anyone who can reach the board can compute a valid MAC from public
      information and flash both processors. Refuse when `pw_len == 0`, and
      surface the condition on `/api/status` next to
      `boot_button_bypass_active` -- the codebase already accepts that "this
      board has no OTA auth right now" must be permanently visible.
- [x] **`POST /api/zones` and `POST /api/rules` are not gated on a running
      firing** DONE 2026-08-27 -- both now run the same
      `ota_http_check_interlocks()` gate as `kiln_cfg_http`'s apply and
      `backup_http`'s restore. Proven both ways on the board: 409 "a profile
      is running" during a firing, 200 for the identical request when idle., unlike `kiln_cfg_http`'s apply and `backup_http`'s restore,
      which write the same `zones_cfg_t`. Changing `relay_mask` mid-run moves
      the firing onto a different physical relay and leaves the old one
      wherever it was last commanded, with nobody driving it off.
- [x] **`/api/status` has ~46 bytes of margin in a 2500-byte buffer, and goes
      ~120 bytes negative if the build strings need escaping.** DONE
      2026-08-27: overflow is now a 500 with a valid body naming the cause,
      matching `zones_http.c`, so the endpoint can no longer emit a truncated
      document however the buffer's margin drifts as fields are added. The
      hand-sizing itself is no longer load-bearing, which was the point.
      `safety_build_commit`/`datetime` arrive over the link from the RP2040, so
      a corrupt or hostile FW_VERSION frame overflows it deterministically ->
      truncated JSON -> the dashboard's "Loading..." hang. Stop hand-sizing
      this one: chunk it (as `profiles_http.c` already does) or return 500 on
      overflow instead of a half-object.
- [x] **`GET /api/profiles` overflows at 8 slots with escape-heavy names**
      DONE 2026-08-27 (`ee38e39`): the per-entry budget is sized against a
      fully-escaped name, a reserve the per-entry writes may not touch keeps
      the document closable, and a dropped entry is reported as an entry.
      (800 bytes needed vs 784 available) producing syntactically invalid JSON.
      Per-entry budget of 96 ignores that a 15-char name escapes to 30.
- [x] **`/api/readiness` drops items silently and can emit invalid JSON.**
      DONE 2026-08-26 (commit 4e8e1f1). A reserve is held back so the closing
      `]}` can never be the thing that overflows; `first` is only cleared when
      the offset actually moved, so a dropped first item can no longer open
      the array `[,`; and any drop now appears AS an item
      (`checklist_truncated`, READY_CANNOT_YET) rather than shortening a list
      an operator reads as a go/no-go. Negative-tested on the board with the
      buffer cut to 900 bytes.
      `append_item` returns the offset unchanged on overflow while `first` is
      set unconditionally, so a failed first item yields `[,{...}`; the closing
      `]}` is skipped on overflow too. ~156 bytes of margin at 12 items.
- [x] **`ota_http.c` and `factory_reset.c` have no host-test coverage at
      all.** DONE 2026-08-27 (`da4918c`) by the first of the two routes this
      item proposed: `ota_http.c` and `factory_reset.c` now compile on the
      host and are `#include`d by an 8th executable, `test_ota_http.c` -- so
      the real decision code is under test, not a restatement of it. The
      blocking surface (`psa/crypto.h`, `esp_ota_ops.h`, `esp_partition.h`,
      `esp_app_desc.h` and friends) is stubbed. The HMAC stub is a documented
      FAKE: it establishes that identical inputs give identical output and
      different inputs do not, which is all the three decisions under test
      depend on -- it is NOT evidence that the real crypto is correct, and its
      header says so. Negative-tested: removing the `pw_len == 0` refusal, and
      making factory-reset reuse `"esp"`'s context, both go red.
      **Still uncovered:** the streaming transfer handlers
      (`ota_esp_do_transfer`, `ota_pico_do_stage`) and the route wrappers
      around them remain hardware-verified only.

- [x] **`httpd_resp_send(req, json, n)` sites use `snprintf`'s return
      unclamped at the high end** -- a stack over-read that sends adjacent
      stack memory to the client if the format ever exceeds the buffer. DONE
      2026-08-27 (`8782c0a`). The count in this item was wrong: a sweep of
      every `httpd_resp_send(req, buf, count)` in `App/drivers/` found
      **seven** genuinely unclamped sites, all of them in `ota_http.c`. The
      rest either accumulate through an `APPEND` macro that already stops on
      overflow, clamp explicitly (`wifi_provision_http.c`), or pass
      `HTTPD_RESP_USE_STRLEN`. All seven now go through
      `send_json_clamped()`. Negative-tested on the board: with
      `/api/ota/challenge`'s buffer cut to 16 bytes the reply is 15 bytes and
      the log names the undersized buffer; unclamped it would have sent 76.
- [x] **PID zones can command heat with no valid reading.** DONE
      2026-08-26 -- the deferred-on-time payback block moved inside
      `if (sensor_ok[zi])`, matching bang-bang's refusal. The
      deferred-on-time payback block in `profile_executor.c` runs
      unconditionally, outside the `if (sensor_ok[zi])` that zeroes `duty`, so
      a zone that accrued credit under the load cap and then loses its
      thermocouple gets `boosted_duty` up to 1.0. Bang-bang mode explicitly
      refuses this case; PID has no equivalent. >= 3 s of full duty before
      guard 6 debounces.
- [x] **Danger mode leaves relays energized when its window closes.** Both the
      timeout and the operator stop release heat-enable and restore the gate,
      but neither commands the four ESP relays off -- and restoring the gate
      only blocks *new* ON commands. A relay closed during danger mode stays
      closed indefinitely under a gate that would now refuse to close it.
      DONE -- both `danger_mode_stop()` (`danger_mode.c:255-282`) and the
      timeout path in `danger_mode_task()` (`danger_mode.c:290-318`) now call
      `kiln_io_owner_command_all_relays_off()` before restoring the gate.
- [x] **Fault sources asserted by `autotune_engine` and by guard 9 are never
      deasserted.** Neither has the `global_fault_source` bookkeeping
      `profile_executor` uses, and nothing else clears an arbitrary source, so
      one autotune trip or one 10-second executor stall blocks all heat
      board-wide until reboot -- and masks any later, different fault. DONE
      -- `autotune_engine.c:1009-1035` (this was around line 3193 before
      later edits shifted the file) clears a stale zone/global fault
      source on the next autotune start, and
      `profile_executor_relay_io.c:555-568`'s `clear_this_runs_faults()`
      deasserts `s_exec.global_fault_source` on every exit from a run.
- [x] **Guard 5's absolute ceiling is off by default.** `max_temp_c == 0` means
      "no ceiling", and a zone never saved through `/settings/zones` fires with
      none -- while `autotune_engine` and `SAFETY_MODEL.md` both already assume
      the guard is armed. Either substitute a hard ceiling or refuse to start a
      firing on such a zone. DONE -- `profile_executor_start.c`'s
      `profile_zones_have_ceiling()` now refuses to start a firing on any
      zone that can command heat and has `max_temp_c == 0`, matching
      `autotune_engine_run_relay()`'s existing guard-5 refusal for the same
      reason (host-tested in `test_profile_executor_prestart.c`).
- [x] **A completed run never releases its relay ownership** (only
      `profile_executor_halt()` does), so after a normal finish every manual
      relay command is refused as "owned by a profile" when none is running.
      DONE -- duplicate of the DONE item above ("A completed or faulted run
      never releases its relay ownership", 2026-08-26): `release_profile_
      relay_claim()` is called on every exit from RUNNING
      (`profile_executor.c:501,620,1253`).
- [x] **`rules_task` applies zone calibration with a channel index** where the
      executor correctly combines raw then applies once with the zone index --
      so a rule threshold means a different temperature than the control loop
      on any multi-thermocouple zone. MOOT -- `rules_task.c` no longer exists.
- [x] **`IO_CMD_SX_LED_DRIVER` can PWM a relay coil with no safety gate, no
      ownership gate and no remap**, and never updates `relay_shadow` -- so the
      dashboard reports the coil off while it is energized. Its two immediate
      neighbours in the same switch both check `kiln_io_relay_pin_mask()`.
      `IO_CMD_SX_RESET` and the pullup/opendrain/int-mask setters have related
      gaps. DONE -- `IO_CMD_SX_LED_DRIVER` is now unconditionally refused on
      any relay pin (`kiln_io_owner.c:253` `sx_led_driver_touches_relay()`/
      `:422`, `uart_bridge_io.c:497-521`), matching its neighbours rather than
      trying to retrofit a duty-cycle onto a mechanical coil.
- [x] **`board_temps.c` labels cold-junction readings by array position**, but
      `MAX31856_read_all()` compacts over failed channels -- so with channel 0
      dead, channel 1's reading is displayed as "ch 0" and the dead channel is
      not the one shown absent. Index by `.channel`, as
      `ui_page_thermo_faults.c` already does. DONE -- `board_temps.c:90-129`
      now indexes `thermo_cj_valid[]`/`thermo_cj_c[]` by `r->channel`, never
      by loop position.
- [x] **A CJRANGE fault NaNs only the cold junction**, but the hot-junction
      value is cold-junction-compensated in hardware -- so an out-of-range cold
      junction yields a wrong hot-junction temperature reported as a plausible
      number. DONE -- `max31856_fault_invalidates_tc()` (`max31856_codec.h`)
      now also NaNs `tc_temperature_c` on a CJRANGE fault; see
      `MAX31856.c`'s read path (~line 1121) and its 2026-08-27 doc comment.
- [x] **`dashboard_get_status()` calls `kiln_io_read()` from the LVGL task**,
      bypassing `kiln_io_owner` and consuming the SX1509 interrupt latch that
      another reader may be waiting for. DONE (not one of the original 12 in
      this pass's assignment, but fixed as part of it) -- routed through
      `kiln_io_owner_command_read()` (`dashboard_http.c:146`). Checked for the
      flash-worker-style self-deadlock first: this handler only ever runs on
      the httpd worker task or the LVGL task, never on `kiln_io_owner`'s own
      `owner_task`, and `post_and_wait()` fails closed on a bounded timeout
      (`KILN_IO_OWNER_WAIT_MS`) rather than blocking forever -- no reentrancy
      risk found.
- [x] **`spi_owner_transfer()` waits `portMAX_DELAY`**, defeating every
      caller-side timeout above it if the owner task wedges. DONE
      (`DISPLAY_ST7796_PLAN.md` Phase 1): bounded to
      `SPI_OWNER_TRANSFER_TIMEOUT_MS` (1000 ms) backed by a heap slot pool
      (`owner_slot_pool.h`), with a `wedged` latch surfaced on `/api/status`
      as `thermo_spi_wedged` and a banner in `main_page.html`.
- [x] **`gpio_probe`'s deny-list omits the three `~FAULT` pins**, so a probe
      session can drive them high permanently and forge "no fault" at the pin
      level. DONE (not one of the original 12 in this pass's assignment, but
      fixed as part of it) -- `THERMO_FAULT0_IO`/`THERMO_FAULT1_IO`/
      `THERMO_FAULT2_IO` added to the deny-list (`gpio_probe_denylist.h`,
      called from `gpio_probe.c`), negative-tested in `test_gpio_probe.c`
      (removing the three entries makes all three checks fail, confirmed and
      reverted).
- [x] **Docs contradicting code: fixed.** `KilnFW/docs/HARDWARE.md` now
      records both the thermocouple channel rotation and the relay 2<->4
      swap, in the SX1509/relay section and the thermocouple daughterboard
      section respectively.

---

This is a planning doc: it tracks work not yet done, plus enough context on
finished, adjacent work to act on what's left. A finished section is
collapsed to a short status line pointing at the doc that owns its detail —
`docs/PROJECT_STATUS.md` (dated engineering log), `docs/ARCHITECTURE.md` /
`docs/ARCHITECTURE_DECISIONS.md` (settled design), `docs/BRINGUP_HAZARDS.md`
(recurring bugs and their root causes), `docs/PID_CONTROL.md` +
`docs/GUARD_TEST_MATRIX.md` (control loop and thermal-safety detail), and the
per-feature docs (`WEB_UI.md`, `WIFI_PROVISIONING.md`, `PROFILES.md`,
`SAFETY_MODEL.md`, `UI_PLAN.md`, `UI_THEME.md`). **Most of the "still open"
items below are open specifically because no ESP32-S3/RP2040/thermocouple/
relay hardware combination exists in this environment to verify them
against** — treat "logic-verified"/"build-clean" language literally, not as
a synonym for done. Cross-references `docs/SAFETY_MODEL.md` throughout,
since the profile-execution engine here is a **new actor that commands
relays** and must go through the same safety-wins gate as the existing
PC/MCP link — not a parallel path that bypasses it.

## 0. Architecture decisions

**All settled and built.** Full writeup moved to
[`docs/ARCHITECTURE_DECISIONS.md`](docs/ARCHITECTURE_DECISIONS.md): web
server on-device, relay ownership tags, the rule-engine composition rules,
the history ring buffer design, and storage (NVS, no LittleFS).

**Rule engine — BUILT 2026-08-22.** `rules_eval.{c,h}` (pure decision logic)
plus `rules_task.{c,h}` (1 Hz FreeRTOS task) close the "evaluator has no
caller" gap this line used to record. Precedence is
PROFILE/AUTOTUNE > RULE > MANUAL through the existing `relay_authority`
tags; a safety fault, a down safety link, or an OTA in progress forces every
rule-driven relay off, and turning off is never gated. A stale-tick watchdog
forces the same off-state if the evaluator stops ticking for 5 s.

Scope limit set by the owner the same day, and enforced in three places
(`rules_eval_decide`'s `is_heater_relay` gate, `rules_task`'s per-tick
recomputation of the zone-relay union, and the POST handler's refusal):
**rules may never command a relay assigned to a zone.** Those are PID/
thermocouple-controlled heaters. Rules exist for the non-PID hardware —
reduction flame, vents, blowers — and may still READ heater relays as rule
conditions.

## 0.5 Page organization

Grouping: Dashboard (section 2, home/live status), Profiles (section 5),
Settings split into Thermocouples & Zones (section 3, incl. PID tuning),
Relays & Rules, Network (section 4). Safety-relevant controls stay reachable
in the fewest taps (phone-screen constraint). Built as described.

**Four more pages added to plan 2026-08-18** (web + LCD both):

- ~~**Safety / Alarm page.**~~ **DONE 2026-10-07** (`ui_page_safety.c`, hub cell
  "Safety", tap on the home trip strip): live state, last trip (reason, age,
  cause, remedy) and a Clear Trip button. Viewing is dashboard-level (no PIN);
  Clear needs an LCD admin login (`ui_lcd_lock_run_gated`) and sends the same
  `dashboard_safety_clear_trip()` the web route uses (same refusals). The alarm
  is derived from live DIAG state every refresh (`ui_safety_view_derive`, shared
  with the home strip, host-tested), never a page-local latch, so a clear from
  web/MCP/UART removes it. History is only the last Frame D event (no multi-trip
  ring on the link); the diagnostics Trip Detail page still shows it in full.
  The config hub became 3 columns to fit the extra cell.
- **Diagnostics / System info page — DONE for the ESP-only half; SAFETY-LINK
  STATS HALF STILL BLOCKED ON M5.** `ui_page_diagnostics.c`/`.h` (fw version,
  uptime, heap/PSRAM, die temp) built 2026-08-20. A separate
  `ui_page_thermo_faults.c`/`.h` page (per-channel MAX31856 fault bits,
  visibility only, no clear action) was added the same day per explicit
  request to split diagnostics into multiple pages.
- ~~**Manual zone control page.**~~ **Declined by explicit user request
  (2026-08-20)** — no manual setpoint override bypassing a running profile.
  `ui_page_temperature.c` (per-zone reading + manual relay toggles) stays.
- Backup/restore, LCD tc-type page (`docs/ARCHITECTURE_DECISIONS.md`):
  - [x] **Stale as of 2026-09-22 — closed docs-only, no code gap found.**
        Restore already gates through `ota_http_check_interlocks()`
        (`backup_import.c:2671`, same wrapper `ota_http.c`'s OTA routes use).
        Every `zones_http.h`-exposed field (via `zones_config_accessors.h`)
        has a validating setter and round-trips through
        `backup_import_apply()` — see
        `test_backup_import.c`'s `test_export_round_trips_through_import_to_identical_config`
        (line ~3145), which checks PID gains, tc_type, name, masks,
        cal_offset_c, sanity_rate_c_per_min, control_mode, max/min_temp_c,
        heater_window_ms, fuzzy_strength_pct, coupling_coeff[], the
        coupling_diag_k_dc addition, settings_source and failsafe_state
        individually. `test_wifi_prov.c` and `test_backup_import.c` both
        exist and link `backup_http.c`'s split files
        (`backup_json.c`/`backup_export.c`/`backup_import.c`) and
        `wifi_prov.c` into host tests via the same `#include`-the-.c
        convention used elsewhere in this suite. Matches
        `project_backup_round_trip_coverage.md`'s "only the Wi-Fi password
        is irreducible" note.

**Web page structure rework — DONE (2026-08-20/21).** `settings_page.html`
(now trimmed to just the danger zone), `manual_page.html`, `safety_page.html`,
`diagnostics_page.html`, `thermo_faults_page.html`, a scrollable/LCD-like
dashboard reorder, and the top drop-down nav/Home button chrome rework are
all built — see `docs/ARCHITECTURE_DECISIONS.md` ("Page organization").
Still open, unauthorized-to-build: the session-token auth layer on writes
and TLS for this UI and OTA (section 9.3) — see `docs/UI_PLAN.md`.

## 1. Wi-Fi provisioning and resilience — DONE, hardware-verified

Implemented in `App/drivers/wifi_prov.{c,h}` + `App/drivers/wifi_provision_http.{c,h}`
+ `wifi_provision_page.html`. AP fallback, single home/AP mode toggle (redesigned
2026-08-11 from the original three-flag model), editable AP identity, saved-network
list with forget (section 8.4), DHCP/static IP toggle (web only, 2026-08-20), and the
"losing Wi-Fi never stops the control loop" hard requirement are all built and
hardware-verified — AP-join, station-join, captive portal (real associated client,
DNS hijack + 302 to `/`), and a 35-minute soak with zero failures. Full detail and
every dated fix: `docs/WIFI_PROVISIONING.md` and `docs/PROJECT_STATUS.md`. Several
real bugs were found and fixed during hardware testing this pass (Wi-Fi
mode-switch ordering, `has_creds` disagreement, internal-SRAM task-registration
race, coredump partition sizing, UART log congestion) — condensed writeups in
`docs/BRINGUP_HAZARDS.md` rather than kept here.

Open items, not yet fixed:

- [ ] **AP-fallback fix unverified end to end** (`ARCHITECTURE_DECISIONS.md`,
      "Static-IP AP-fallback fix") — needs a router with both correct and
      deliberately-wrong static config, plus a second device.
- [ ] **Not exercised against a real router**: the DHCP/static toggle is
      build-verified and flashed but has no live network in this environment to
      confirm actual join behavior against.
- [x] **Wi-Fi driver log lines arrive with an empty body** (`W (...) wifi:` with
      nothing after the colon) roughly every 30s. RESOLVED 2026-09-22, not a
      pipeline defect: `uart_log_bridge.c`'s parse/format path
      (`uart_log_parse_level()`, `uart_log_vprintf()`) passes tag/message bytes
      through untouched and reports truncation and drops explicitly, neither of
      which matches this symptom -- it is ESP-IDF's own
      `ESP_LOGW("wifi", "")` inside the closed-source esp_wifi blobs, upstream
      and by design. No content is lost. Optional, not recommended: silence it
      with `esp_log_level_set("wifi", ESP_LOG_ERROR)`.

## 2. Web UI — Main / Dashboard page

DONE and hardware-verified — `App/drivers/dashboard_http.{c,h}`, `main_page.html`.
Live per-channel thermocouple/relay status, the desired-vs-actual graph
(`GET /api/history.csv`, section 6A.9), Start/Stop/Pause, and a saved-profile
picker are all built; all five pages (dashboard + 4 sub-pages) verified live to
be browsable with every card marked hardware-absent when the daughterboard/
expander are missing, rather than crashing or lying. `docs/WEB_UI.md` has the
full page/API inventory.

Idle-state chart behavior: `docs/ARCHITECTURE_DECISIONS.md`, "Idle chart / pinned dots".

- [ ] **Still polled (2s), not pushed.** `CONFIG_HTTPD_WS_SUPPORT` is off; not
      yet justified. Revisit (WebSocket or SSE) if 2s polling proves too coarse
      once real hardware is attached and watched during a firing.
      Re-evaluated 2026-09-25 from source: still not worth it. `.dram0.bss` has
      under 1.5 KB of headroom, a held WS/SSE connection permanently takes one of
      the 13 httpd sockets (the pool has already saturated once from two tabs
      polling), no async-handler pattern exists yet to build it LRU-safe on, and
      there is no path for a session expiring mid-stream. If 2s ever proves
      inadequate, do the cheap wins first: ETag/304 on `/api/status` and a
      slower idle interval, as `pollHistory`/`pollAutotune` already use.
      Also covers the 6A.9 polling note (merged 2026-10-07).
      **Cheap wins landed 2026-10-07:** `/api/status` sends an FNV-1a ETag of
      the rendered body and answers a matching `If-None-Match` with 304
      (`dashboard_etag_*` in `dashboard_json.c`; saves bandwidth/JS parse, not
      render cost), and `main_page.html`'s `poll()` backs off 2 s -> 5 s while
      no firing or autotune is active (`pollDelayMs()`).
- [ ] **Pixel-level appearance of the idle dots was not visually confirmed**
      — no framebuffer readback and the browser was not driven during
      verification; only the API/serving behavior was checked.

## 3. Web UI — Settings page

DONE — `/settings/zones` (`App/drivers/zones_http.{c,h}` + `zones_page.html`) and
`/settings/relays` (`App/drivers/rules_http.{c,h}` + `rules_page.html`, both
removed 2026-08-27 along with the rule engine — see `docs/PROFILES.md`).
Thermocouple calibration (offset, applied in firmware to every consumer including
UART/MCP as of 2026-08-13), thermo/relay count config, named zones, PID tuning
per zone (same page, per explicit request), and persistence are all built and
hardware-verified as reachable/functional with no thermocouple/relay hardware
attached. The relay alternate-function rule *editor* (DSL, `RELAY n DRIVEN`/`R
<rule> TEMP|TIME|RELAY`) is built and persists; the rule *evaluator* that would
make saved rules actually drive relays does not exist — `rules_http.h`'s own
comment and the page both say saved rules are inert (see section 0's rule-engine
design in `docs/ARCHITECTURE_DECISIONS.md`).

Max-ramp-rate ceiling is a **user-entered** value (`max_ramp_c_per_hr`), not
estimated from PID tuning/observed performance — the estimated alternative was
deliberately left undesigned as "more work, needs a design of its own."
(Profile-page °C/°F display and its builder-editable-field seam:
`docs/ARCHITECTURE_DECISIONS.md`, "Profile builder: Celsius-only editable
fields".)

## 4. Web UI — Network settings page — DONE, folded into section 1

Same page as section 1's provisioning page (`wifi_provision_page.html`) rather
than a separate route — scan/select SSID, mode toggle (superseded the original
local-only checkbox 2026-08-11), and live connection-state display are all built.
See section 1 and `docs/WIFI_PROVISIONING.md`.

## 5A. Shipped firing schedules (Digital Fire catalogue) — DONE 2026-08-20

The 28 published schedules at https://digitalfire.com/schedule ship in flash as
read-only profiles (ids `PROFILE_BUILTIN_ID_BASE`+index, separate from the 8 user
slots), hide-not-delete via an NVS mask, generated from a scraper
(`tools/scripts/gen_builtin_profiles.py`/`scrape_digitalfire_schedules.py`) rather
than hand-transcribed, and paged over the size-limited UART LIST command. Credited
on `profiles_page.html` with a source link per entry.

### 5A.1 Feasibility marking — red when the tuning says it cannot be fired

`profile_feasibility.c` judges each segment against the autotune-fitted first-order
model (`dT/dt = (K*u - (T - T_amb)) / tau`): max heating/cooling rate, an
`UNREACHABLE` verdict for a target above `T_amb + K`, and the existing
`max_ramp_c_per_hr` ceiling on top. With no tuned model the verdict is `UNKNOWN`
(never a false OK or false red). Verified on hardware that the badge agrees with
what `profiles_start()` actually refuses. DONE and hardware-verified 2026-08-20.

- [x] **`T_amb` is now each zone's own persisted autotune ambient, not a live
      cold-junction reading (2026-09-05, reworked — the 2026-09-05
      live-cold-junction version below was reviewed and rejected same day).**
      `get_persisted_ambient_c()` in `profile_feasibility.c` reads
      `zone_tuning_quality_t::baseline_c` via `zones_config_get_tuning_quality()`
      — the settled chamber temperature autotune measured immediately before
      that zone's identification step began (`fopdt_model_t::baseline_c`,
      `pid_autotune.h`) — and falls back to the `FEASIBILITY_AMBIENT_C`
      constant (20 C) whenever `tuning_valid` is false, `method` is not
      `AUTOTUNE_METHOD_STEP`, the getter cannot answer, or the stored value
      is non-finite or outside `[5, 60]` C. Sampled once per public entry
      point (`profile_feasibility_segment_in_mask()`,
      `profile_feasibility_profile_in_mask()`) and threaded down as a
      parameter, so every segment of one profile walk sees the identical
      value even though `start_c` and `t_amb` used to be sampled at two
      separate call sites. Pure config lookup — no I/O, no lock, no cache,
      nothing that can go stale between calls.

      **2026-09-05 Opus review fix (of the `baseline_c`/`step_ambient_c`
      choice above, and of the `[0, 60]`/no-method-gate range check):** the
      field originally read here was `step_ambient_c` (a cold-junction
      reading), documented as "the ambient the fitted model is relative to"
      — which was wrong. `k_dc` is fitted in `autotune_finalize_fit()` as
      `raw_rise_c = final_c - baseline_c`, i.e. relative to `baseline_c`
      (the settled *chamber* reading), not the cold junction, which sits
      1.6-2.0 C below chamber per `autotune_engine_step_identify.c:920`.
      Mixing the two zero points skewed every ceiling by that gap. Switched
      to `baseline_c`, the field the fit is actually relative to.

      Separately, MAJOR: `zone_tuning_quality_t::step_ambient_c` (and
      `baseline_c`) is zeroed to `0.0f` at the start of every autotune run
      (`autotune_engine.c` ~line 1090) and is only ever given a real value at
      the SETTLING→STEPPING transition of a STEP-method run (~line 597); the
      old `[0, 60]` range check let that `0.0f` sentinel pass as a plausible
      cold-room reading, silently dropping the computed ceiling by 20 C.
      Fixed two ways: the range floor moved to `[5, 60]` (0.0 no longer
      passes on its own), and `q.method == AUTOTUNE_METHOD_STEP` is now
      required explicitly as defence in depth — `zones_config_
      set_tuning_quality()` is, as of this review, only ever called from the
      STEP-method accept path in `autotune_engine_guard.c` (the RELAY branch
      returns before that call, since a relay test fits no FOPDT model to
      attach a quality record to), so today the method check is always true
      for any `valid` record; it guards against that call site ever changing,
      or a stub/future caller reaching the getter with a RELAY-shaped record.
      Both breaks (dropping the `valid` check; dropping the `method`+range
      check) were confirmed to redden `test_profile_feasibility.c` by hand
      before being reverted — see that file's own tests for the receipts.

      **Why the live cold-junction version (below) was wrong, not just
      differently implemented:** Opus review the same day rejected it on
      four independent grounds — ~300 B of added stack on the httpd and LVGL
      tasks, both already near-overflowed elsewhere in this codebase; the
      LVGL task blocking up to `THERMO_OWNER_WAIT_MS` on the same SPI bus the
      display uses, from inside a render path; the ambient cache
      (`s_ambient_cache_c`/`_last_us`) being a plain, non-atomic pair
      written by whichever task called in and read by every other, i.e.
      torn under concurrent access with nothing serialising it; and,
      decisively, wrong physics — a MAX31856 cold junction reads the
      **board's own temperature**, which self-heats over the course of a
      firing, so using it as "ambient" would inflate the computed ceiling
      exactly when a firing is running and the check matters most.
      `autotune_engine_step_identify.c` (around line 920-935) already
      documents rejecting the cold junction as an absolute reference for
      this same reason — the live-ambient version above re-introduced
      exactly the input that file explicitly avoids. The tests added
      alongside the live version also never executed the live-reading
      branch (the stub always returned "no reading"), so the one bit of
      behavior that actually changed shipped unverified.

      Bench check 2026-09-05: `GET /api/zones` on the live board shows all
      three zones with `tuning_valid: false` (baseline/ambient fields
      unpopulated) — no zone has ever been autotuned with this record
      populated, so today every zone still gets the 20 C fallback in
      practice. The fix is correct and in place regardless; it starts
      mattering as soon as a zone is next STEP-autotuned and this record
      gets a real `baseline_c`.

      **Also documented here (not itself a code change):** any later write
      to a zone's PID gains — an accepted autotune of either method, an
      adaptive-tune adjustment during a normal firing, a backup import, or a
      manual edit — clears `tuning_valid` unconditionally
      (`zones_config_set_pid()`, `zones_config_accessors.c` ~line 401), which
      reverts that zone's feasibility ambient to the 20 C fallback until the
      next accepted STEP autotune. This is expected, conservative behaviour
      (an unreachable ambient is safer than a stale one) and is deliberately
      not being changed here — see this task's own constraints.

      Tests drive `test_stub_zones_set_coupling()`-style stub hooks
      (`stub_zone_ambient()`/`stub_zone_ambient_method()` local to
      `test_profile_feasibility.c`, backing the file's own
      `zones_config_get_tuning_quality()` stand-in) covering: a persisted
      30 C ambient reaching a 70 C target the 20 C fallback calls
      `UNREACHABLE`; getter failure, NaN, and out-of-range (80 C) all
      falling back to 20 C; `tuning_valid == false` with an otherwise
      in-range `baseline_c` (30) falling back; the `baseline_c == 0.0f`
      sentinel specifically falling back even with `valid == true` (the
      2026-09-05 review's MAJOR finding, now caught by the `[5, 60]` floor);
      a RELAY-method record with an in-range `baseline_c` falling back (the
      method-gate defence in depth); and two zones in the same profile
      judged independently against their own persisted ambients.
      Negative-tested two ways: reducing `get_persisted_ambient_c()` to
      `return FEASIBILITY_AMBIENT_C;` unconditionally (confirms the
      ceiling-raising and per-zone tests go red), and separately dropping
      just the `valid` check and just the `method`+range check (each
      confirmed, by hand, to redden a distinct test before being reverted).

- [ ] **One global bridge stall in a 25-minute soak (2026-08-20), cause not
      found.** 78 polling ticks, 77 clean; at t=1031s EVERY bridge surface
      (control/profiles/autotune/wifi/touch) failed in the same tick — "ACKed but
      no reply within 3.0s" — then the next tick was clean. The ACK proves the
      link/owner task were alive, so whatever blocked was downstream of frame
      delivery and hit all five task inboxes at once — the shared flash-safe
      executor only serialises control/profiles/autotune, so it cannot alone
      explain wifi/touch stalling too. Suspect a long flash/NVS op or the
      log-bridge queue backing up. Not reproduced since. Worth a targeted soak
      logging per-surface latency percentiles rather than pass/fail.

### 5A.2 Still open

- [x] **UNREACHABLE test edge fixed.** The steady-state ceiling test is now
      gated on `target > start_c` (rising only) in `profile_feasibility.c`;
      see `test_ceiling_test_gated_to_rising_segments` in
      `test_profile_feasibility.c`.

LCD profile access (browse/select/start) and the flash-headroom constraint
that used to block it are both done — see `docs/ARCHITECTURE_DECISIONS.md`
("Page organization") and §9.1 above for the reworked partition table.

## 5. Web UI — Fire profile creation page

DONE — `App/drivers/profiles_http.{c,h}` + `profiles_page.html`. Profile editor
(name, up to 12 segments of target/ramp-rate/dwell, `zone_mask`), save/load/delete
(8 NVS slots, versioned per section 8.2, same handlers the UART CONTROL bridge
uses), sanity-bound validation, and the feasibility check against each zone's
`max_ramp_c_per_hr` (hard reject over ceiling, warn within 20% margin) are all
built. The feasibility check re-running at profile-*start* time (not just save
time) is closed by section 6A.7's mid-firing ceiling re-check.

## 6. Firmware-side profile execution engine (implied by sections 2 and 5)

DONE — `App/drivers/control/profile_executor.c`, 1Hz tick. Segment stepping/ramp
interpolation, per-zone `OFF`/`BANGBANG`/`PID` control mode (live-reloadable
since 2026-08-12), the direction/rate sanity monitor (thermal_guard.c guards 1/2,
full detail in section 6A.3), relay-authority gating, fail-toward-off on pause,
and preemption by every existing safety mechanism are all built. Guards 1/2/4/7
are written but not yet exercised live (no thermocouple hardware to provoke
them) — tracked as a hardware-verification gap in section 6A.3/6A.8, not
reopened here.

## 6A. PID control, thermal protection, autotune, and zone interaction

**Status: built and hardware-verified where a thermocouple/kiln exists to verify
against; a large slice remains logic-verified only for lack of hardware.** Full
design and current status: `docs/PID_CONTROL.md` (control loop, guard table,
autotune flow, host-test summary) and `docs/GUARD_TEST_MATRIX.md` (one row per
guard: provocation, threshold, expected trip time, what the operator sees).
This section now only tracks what remains open.

Built: `pid.c` (positional PID, derivative-on-measurement, low-pass D filter,
anti-windup, functional-range blending, bumpless transfer at every
discontinuity, feedforward from the identified plant model, 2-DOF setpoint
weighting); `thermal_guard.c` (all 9 Klipper/Marlin-class guards, see
`docs/GUARD_TEST_MATRIX.md`); `heater_output.c` (time-proportioned duty,
min-on/off, contact-cycle accounting, phase-offset load staggering,
`max_simultaneous_relays` cap with deferred-not-dropped credit); `pid_autotune.c`
+ `autotune_engine.c` (step-test FOPDT fit + SIMC/ZN/Tyreus-Luyben tuning,
relay-feedback identification, cross-zone coupling-matrix capture, RGA display);
concurrent multi-zone execution with ramp-lock; the per-zone relay-authority
gate (6A.6); mid-firing config reload with bumpless transfer per field; a
host-side kiln plant simulator (`App/test/sim_plant.c`, multi-zone, injectable
faults) plus an on-target `KILNCTL_SIM_PLANT` build option
(`App/drivers/sim_backend.{c,h}`) for exercising the whole chain without real
hardware.

**Never run against a real firing.** No thermocouple/relay hardware has ever
completed the guard-provocation walk against real elements — every guard
proof to date is either a host-simulator test or, on the bench, guard 6
(sensor-invalid, trivially reachable with no thermocouple attached at all).
Treat every "implemented" claim in the linked docs as logic-verified unless
its own text says otherwise.

### 6A.0 What already exists to build on

See `docs/PID_CONTROL.md`'s module table. Two facts from `docs/HARDWARE.md`
that constrain the design: relays are EE2-12NUH electromechanical parts on
12V coils (expander pin high = energized), each on a 3-pin terminal block; a
"duty cycle" is therefore a slow time-proportioned window over I2C, not PWM.

- [x] **ANSWERED 2026-08-24 (owner): the on-board relays exist for galvanic
      isolation and switch other relays only.** They never carry element
      current. The part itself makes this unambiguous -- K1-K4 are
      **EE2-12NUH, a KEMET EC2/EE2 miniature SIGNAL relay**
      (`hardware/datasheets/mainBoard_Relay/EE2-12NUH.pdf` p7): max switching
      current **2 A**, max switching power **60 W / 125 VA**. A kiln element
      is kW-scale at tens of amps, so this relay physically cannot switch one
      and was never intended to.

      **Consequence for the duty window:** the pessimistic ~1e5-op budget this
      section assumed does not apply. The datasheet's loaded running spec is
      **1e6 operations** (50 VDC 0.1 A resistive, 85 degC, 5 Hz), with
      non-load life 1e8 and stable characteristics to 1e7 -- pilot duty into
      an SSR input or a small coil sits at the easy end of that. Taking 1e6 as
      the budget and one operation per window: a **10 s window** spends it in
      ~2,800 hours of *continuous* firing (~116 days), i.e. over a decade at
      40 h/week. A 2 s window still gives ~555 hours continuous (~2.7 years at
      40 h/week). So the window is a control-quality decision now, not a
      contact-life one; 10 s is comfortable and shorter is viable.

      Operate ~2 ms / release ~1 ms, so switching latency is irrelevant at any
      window we would pick.
- [ ] **New, narrower open question this raises:** what does each relay
      actually drive, and what is ITS switching cost? The on-board relay is no
      longer the limiting part -- the downstream device is. An SSR input is
      effectively unlimited; a mechanical contactor has its own electrical
      life (typically 1e5-1e6 ops) which then dominates the window choice.
      **Also a real ratings check, not a formality:** if a downstream
      contactor coil is 240 VAC, the relay's 125 VA switching limit allows
      only ~0.52 A at that voltage, and contactor coil INRUSH can exceed
      sealed current several-fold. Confirm the coil's inrush VA against the
      125 VA limit before driving one directly.

### 6A.1 Actuator model: time-proportioned output, not bang-bang

DONE — `App/drivers/heater_output.{c,h}`. Per-relay `window_ms`/`min_on_ms`/
`min_off_ms` (page-configurable per *zone*, not yet per individual relay —
see 6A.9), anti-chatter (an unachievably-short on-time renders as OFF, not a
minimum pulse), and NVS-persisted contact-cycle accounting (saturates rather
than wraps, exposed on Settings → Relays & Rules) are all built. Window
phase-offset across zones (load staggering) shipped as part of 6A.5.

### 6A.2 The PID loop itself

DONE — `App/drivers/pid.{c,h}`, pure C (no FreeRTOS/ESP-IDF/logging/I/O), so
it is host-testable against the simulator. See `docs/PID_CONTROL.md` for the
full form (derivative-on-measurement, anti-windup, functional-range blending,
bumpless transfer, feedforward, setpoint weighting). The
"cannot follow, cooling-limited" diagnostic is built
(`profile_exec_zone_status_t.cooling_limited`, exposed on `/api/control`) but
not yet exercised live — needs a real ramp-down faster than natural cooling,
which needs either a real kiln or `KILNCTL_SIM_PLANT` (neither run this pass).

### 6A.3 Thermal protection — the Klipper/Marlin-class safety suite

DONE — `App/drivers/thermal_guard.{c,h}`, a pure function of
`(setpoint, reading, commanded_duty, dt, guard_state)`. All 9 guards
(heating-failed, wrong-direction, runaway-with-heat-off, drift-at-setpoint,
absolute limits, sensor validity, frozen sensor, cross-zone plausibility,
control-tick liveness) are implemented, latch until an explicit operator
clear, fail toward off with retry, and escalate to the global fault mask or
a per-zone block as appropriate. `continue_on_zone_trip` (default: abort the
whole firing on any zone's trip) is configurable. Full per-guard status,
including which guards have been observed firing (guard-precedence findings:
several guards overlap on the same physical failure and the shortest window
wins — see `docs/GUARD_TEST_MATRIX.md`), lives in that doc, not here.

- [x] **Owner decision, 2026-09-28: thermal protection gets no disable
      switch, ever.** No per-firing-acknowledgement/Kconfig gate design is
      needed since no "disable thermal protection" affordance will exist.
- [x] **Guard thresholds are per-zone config.** The first eight closed
      2026-08-16 (`zone_cfg_t`, `zones_page.html`'s "Advanced guard
      thresholds" disclosure). The rest closed 2026-08-26 at the owner's
      request ("i dont realy like magic numbers"): guard 1's arming duty and
      no-progress window, guard 4's drift band, guard 7's frozen epsilon and
      guard 8's period are now per-zone fields too, alongside the executor's
      bang-bang band, cooling-limited margin/hold and ramp-lock band, and the
      one global PC-link abort timeout. Guard 8's period is the notable one:
      it already existed in `thermal_guard_cfg_t` but was never plumbed to the
      API and was passed 0 at the only call site, so it was invisible rather
      than absent. Edited on **/settings/safety**; NVS `ZONES_CFG_VERSION`
      7 -> 8. Every one keeps the "0 = not configured, the module substitutes
      its own named `#define`" convention, so the fallback numbers stay in
      code as the documented defaults and an unconfigured board is unchanged.
      Kconfig-tunable compile-time defaults were never asked for and remain a
      scope note, not a gap.

### 6A.4 PID autotune, for every zone

DONE for the step-test path (recommended first, per this section's original
reasoning: slow relay-cycling oscillation is thermally abusive on a kiln at
cone temperature) and for relay-feedback identification's math and on-target
state machine. `pid_autotune.c` + `autotune_engine.c`. Full detail in
`docs/PID_CONTROL.md`. Never run against real hardware — every on-target
autotune run aborts on guard 6 (sensor-invalid) before reaching a fit, since
no thermocouple is attached in this environment.

- [ ] **Gain scheduling by temperature band.** A kiln's plant gain is
      strongly temperature-dependent (radiative loss ~T^4). v1 ships a single
      band per zone, by design — `zone_cfg_t`/the NVS blob would need a band
      array to add this without a storage migration, and don't carry one yet.
      Also owns the Settings → Thermocouples & Zones page remainder (per-band PID
      gains/fitted model UI), merged here 2026-10-07 from section 6A.9.
- [x] DONE: predicted ramp ceiling adoption. `autotune_engine_accept(opts, out)`, with
      `opts->adopt_ceiling` set (autotune_engine.c/.h), writes `max_ramp_c_per_hr` via the
      existing `zones_config_set_max_ramp()` when requested; `POST /api/autotune/accept`'s optional
      `adopt_ceiling=1` form field and a checkbox next to the Accept button on `/settings/zones` opt in,
      default false.

### 6A.5 Multi-zone interaction — "they are not really separate"

DONE for (a) detuned decentralized PID (concurrent multi-zone execution),
(b) coupling-matrix capture during autotune, (c) RGA display, and (d)
ramp-lock/setpoint governor — all hardware-unverified for lack of a real
cross-gain to measure against (the math is exercised by the host simulator's
coupled two-zone model). Electrical load staggering (phase-offset windows +
`max_simultaneous_relays` cap with deferred-not-dropped credit) is also
built. Full detail in `docs/PID_CONTROL.md`.

- [ ] **(e) Static decoupler / cross-feedforward** using the measured coupling
      matrix. Targeted for v1.5, after (a)-(d) are proven on a real firing,
      gated on the RGA from (c) saying it's warranted.
- [ ] **Cross-zone plausibility guard's threshold (6A.3 guard 8) still
      defaults to 0 (disabled).** The guard's logic is built and host-tested;
      what remains is informing the threshold from a measured coupling
      matrix rather than a hand-picked constant, which needs either a real
      matrix (no thermocouple hardware to capture one) or an operator
      willing to enter a number for their own kiln. Its *period* stopped
      being hardcoded on 2026-08-26 (`guard_cross_zone_period_s`,
      /settings/safety); the delta that arms the guard is what still needs a
      measurement.
- (f) Full MIMO / model-predictive control: **decided out of scope** — the
  benefit over (a)+(d)+(e) doesn't justify the cost on a plant this slow, and
  there's no way to validate it safely on a device that fires unattended.
  Not open work, recorded as a decision.

### 6A.6 Safety plumbing that has to change

DONE: per-zone relay-authority blocking (`relay_authority_zone_blocked()`
layered on the global gate), the `THERMO`/`THERMAL_SANITY` fault-source
split, and closing the `SX_WRITE_REG`/`SX_SET_DIR` gate bypass. See
`docs/SAFETY_MODEL.md`'s updated summary table.

DONE (2026-08-21, `relay_authority.h`'s `relay_owner_t` — this bullet was
left open after the fix landed): **ownership tags are a real enum**
(`RELAY_OWNER_NONE`/`MANUAL`/`PROFILE`/`RULE`/`AUTOTUNE`), not just section
0's prose. `autotune_engine.c`'s `begin_run_locked()` claims
`RELAY_OWNER_AUTOTUNE` on the zone's relay mask for the duration of a
step-test/relay-test run; `force_relays_off()` — the single chokepoint every
terminal path (`finalize_fit()`, `finalize_relay_fit()`,
`escalate_and_abort()`, `abort_locked()`) calls before leaving a running
state — releases it, so a claim cannot outlive an aborted run. A manual
`SET_RELAY`/`SET_RELAY_MASK` against an autotune-owned relay is refused with
a reply (`kiln_io_owner.c`'s `relay_authority_manual_blocked_by_owner()` ->
`uart_bridge.c`'s `bridge_reply_reject(..., "owned")`, same wording as the
existing `PROFILE` case), not silently dropped. Safety keeps precedence:
`relay_authority_zone_blocked()`/`relay_authority_on_blocked()` are checked
first and their block is final regardless of ownership. **2026-09-04
correction: no longer true when danger mode is active.**
`kiln_io_owner.c`'s `relay_on_blocked()` checks `danger_mode_active()` first
and, if set, skips both `relay_authority_on_blocked()` and the OTA
heat-interlock check entirely (still logging a warning when one of them
would otherwise have blocked) — deliberately, per `danger_mode.c`'s and
`danger_mode.h`'s top comments, so an operator who has explicitly accepted
the risk can bench-test a relay/contactor with nothing fighting the test.
This is this ESP's own relay-on gate only; it does not touch SaftyFW's
independent contactor authority, which stays outside this board's reach
either way (`danger_mode.h`'s top comment). Host-tested in
`test_autotune_engine_prestart.c` (claim-on-start, release-on-guard-trip,
release-on-manual-abort, each proven able to fail by temporarily disabling
the release call and watching the new checks fail). Not host-tested: the
`uart_bridge.c`/`kiln_io_owner.c` refusal-with-reply path itself — neither
file is part of `build_host_tests.ps1`'s harness (FreeRTOS-task-shaped code,
not pulled in host-side anywhere today), so that leg is verified by reading
the code, not by a test that can fail.

### 6A.7 Task, timing, and module layout

DONE: all five modules exist (`pid.c`, `thermal_guard.c`, `heater_output.c`,
`pid_autotune.c`, `profile_executor.c`); 1Hz tick reading all channels once
per tick; task priority tied with the UART bridge tasks, below the
link-loss watchdog (closest achievable match to "above bridge, below
watchdog" given FreeRTOS priority integers); calibration applied on the
control path with guards seeing raw readings; mid-firing config reload with
per-field bumpless-transfer/cold-restart/immediate-apply rules; an
unowned-relay sweep; and the mid-firing `max_ramp_c_per_hr` re-check (warns,
doesn't block or re-run feasibility).

- [x] **The tick must not block** — both bus accesses go through the
      existing `i2c_owner`/`esp_spi_owner` queues with bounded timeouts, but
      whether a timeout is actually treated as a bad read (feeding guard 6's
      debounce) rather than skipping guard evaluation was never confirmed by
      reading `MAX31856_read_all()`'s timeout contract. CONFIRMED 2026-09-04
      by reading the code: a channel lock timeout surfaces as
      `MAX31856Reading.spi_failed`, and `profile_executor_run.c` (e.g.
      lines 601-602, 645) treats `spi_failed`/`isnan()` readings as bad --
      feeding guard evaluation rather than being skipped.

### 6A.8 Verification — how any of this gets trusted

DONE: host plant simulator (single- and multi-zone, injectable faults),
on-target `KILNCTL_SIM_PLANT` build option, host unit tests for `pid.c`/
`thermal_guard.c`/`heater_output.c`/`sim_kiln.c` (see `docs/GUARD_TEST_MATRIX.md`
for the coverage table), and autotune validated against the simulator's known
ground truth. The on-target guard walk (start a profile, inject each fault
over `POST /api/sim`, watch the right guard trip) has not been performed —
was blocked by DRAM exhaustion (see `docs/BRINGUP_HAZARDS.md`), now fixed but
not yet exercised.

- [ ] **Bench test before kiln test**: a small resistive load and a
      thermocouple (soldering-iron element, heat gun into a can) to exercise
      the whole chain — real SPI reads, real I2C relay writes, real timing —
      at temperatures that cannot hurt anything.
- [ ] **First real firing is attended, low-temperature, and logged**, with
      the history/trace export (6A.9) reviewed afterward before anything
      runs unattended.

### 6A.9 UI and telemetry additions this section implies

DONE: history ring buffer gains `duty`/guard state; the dashboard graph
overlays desired/actual/duty with guard trips marked; `GET /api/control`
live status endpoint; CSV export of history and autotune traces (paginated
after an early out-of-memory bug, see `docs/BRINGUP_HAZARDS.md`).

- [x] **Settings → Thermocouples & Zones page is only partially grown to
      match this section.** Control mode, `max_temp_c`/`min_temp_c`, per-zone
      heater timing, and a working autotune card are on the page. Bang-bang
      hysteresis is DONE -- exposed per-timing-profile as
      `bangbang_hysteresis_c` (`zones_http_handlers.c:250-257`), no longer
      hardcoded. **CLOSED 2026-09-22:** the six always-emitted, POST-round-
      tripped per-zone scalars that had zero renders anywhere on the page --
      `coupling_diag_k_dc`, `ease_off_window_mult`, `approach_rate_cap_c_per_hr`,
      `error_band_c`, `rate_band_c_per_s`, `progress_band_c` -- now render
      under two own-value (no inheritance group) disclosures, "Coupling
      diagnostic gain" and "Controller bands & shaping", and round-trip on
      save; covered by `test_zones_type_toggle.js`. Still missing: per-band
      PID gains/fitted model (gain scheduling is unbuilt, 6A.4) -- the only
      remaining part of this line item.
      MERGED 2026-10-07 into the "Gain scheduling by temperature band" item
      (6A.4): that is now the single tracker; this checkbox is closed.
- [x] **Per-relay `window_ms`/`min_on_ms`/`min_off_ms`** — CLOSED
      2026-09-20, deliberately kept per-zone, not implemented per-relay.
      `zones_config_json.h`'s `zone_cfg_t::heater_window_ms` comment (added
      alongside this field) already gives the reason: a zone's relay group
      is switched as one unit by a single `heater_output_cfg_t` decision in
      `profile_executor.c`/`autotune_engine.c` — there is no
      per-individual-relay timing concept anywhere in the control path to
      hang independent values off of. Building one would mean decomposing
      a multi-relay zone's single duty-cycle decision into independently
      timed sub-relay control, a control-path redesign, not a config/UI
      addition — out of scope for this line item.
- [x] The 2s dashboard polling revisit -- MERGED 2026-10-07 into the "Still
      polled (2s), not pushed" item in section 2 (single tracker).

### 6A.10 Suggested build order

Reference only, all steps through PID mode + feedforward + autotune + RGA
+ ramp-lock have shipped. Remaining: cross-feedforward decoupler (6A.5e),
load-staggering refinements, relay-feedback autotune as the routinely-used
alternate method.

### 6A.11 Open questions, collected

- [x] Do the on-board relays switch elements directly or drive external
      SSRs/contactors? **ANSWERED 2026-08-24: galvanic isolation only, they
      switch other relays.** K1-K4 are EE2-12NUH signal relays (2 A / 125 VA
      max), so element switching was never physically possible. Duty window is
      now a control-quality choice, not a contact-life one — see 6A.0 for the
      arithmetic and for the narrower question it replaces (what the
      downstream device is, and its coil inrush against the 125 VA limit).
- [ ] Element power per zone and total supply/breaker capacity — decides
      whether load staggering (6A.5) is mandatory or optional.
- [ ] Maximum rated temperature of the kiln and of the thermocouples fitted
      (guard 5's `max_temp_c` is mandatory config; it needs a real number).
- [ ] Is there any active cooling or a vent that materially changes the
      plant (the rule engine can drive a vent relay — if it does, the
      identified model is only valid for one vent state, which the autotune
      procedure must record and the docs must state).
- [x] ~~Physical zone arrangement~~ — **answered 2026-09-03, owner-confirmed.**
      Stacked vertically as rings up the chamber wall; zone 2 is the BOTTOM
      element, zone 0 the TOP (zone 1 middle). Corroborates the coupling
      matrix's measured asymmetry (zone 1 leaks into zone 0 harder than the
      reverse). See `firmware/KilnFW/docs/HARDWARE.md` "Physical zone
      arrangement (test kiln)".
- [ ] The sanity rate the request deferred ("I will determine later"), plus
      first-pass values for every other threshold in 6A.3 — the current
      defaults are engineering guesses, explicitly labeled as such.

## 7. Documentation

DONE — `docs/WEB_UI.md`, `docs/WIFI_PROVISIONING.md`, `docs/PROFILES.md`,
`docs/PID_CONTROL.md`, `docs/GUARD_TEST_MATRIX.md`, and `docs/SAFETY_MODEL.md`'s
relay-caller summary table are all written and current. Keep them updated as
their subject areas change (see each doc's own dated-entry convention).

## 8. Storage partitioning, boot-time compatibility, and setup UX

**All five asks from this section are built** (per-concern NVS partitions,
boot-time version compatibility, the config-wizard/readiness page, and the
network status/saved-networks page). Requested 2026-08-12 after a board with
valid credentials reported itself unprovisioned. What remains open below is
purely hardware verification — none of it has touched a physical board.

### 8.1 One partition per concern

DONE — `wifi_nvs`, `kiln_nvs` (zones/rules/relay_cycles/run_state), and
`profiles_nvs` are split (`partitions.csv`), each with its own one-time
migration from the old shared default `nvs` partition (old copy never
deleted, so a rollback still finds working data), and each module owns its
own `nvs_flash_init_partition()`/`nvs_flash_erase_partition()` — no more
blanket `nvs_flash_erase()`. `POST /api/factory_reset` (`App/drivers/
factory_reset.{c,h}`) resets by scope (`wifi`/`kiln`/`profiles`/`all`), a
clean 400 on a missing/unrecognized scope, erase-then-reboot.

- [ ] **Factory-reset erase-then-reboot cycle not exercised on real
      hardware** — in particular, whether the "ok, rebooting" HTTP response
      reliably reaches the browser before the socket drops.

### 8.2 Boot-time compatibility check for every non-volatile section

DONE — every persisted structure (`zones_cfg_t`, rules, profiles,
relay-cycles) carries a schema version checked *before* any size-mismatch
wipe (a real ordering bug here was found and fixed 2026-08-13 — the version
check originally ran after the size check, defeating the whole point of a
migration path; exercised for real by the `continue_on_zone_trip` v1→v2
field addition). Three outcomes (load / migrate / refuse-newer-and-keep,
never wipe a newer-than-firmware blob), one boot-time report
(`App/drivers/nvs_report.{c,h}`, `nvs_sections` on `/api/status`,
partition-granularity only), and `zones_config_is_valid()` gating
`profile_executor_run()`/`autotune_engine.c` are all built.

`rules_http.c`/`relay_cycles.c`/`profiles_http.c` share the same
version-vs-size-ordering pattern as the pre-fix `zones_http.c` bug — not
independently fixed since none of them needed a field added this pass; fix
the same way whichever future change actually grows one of those structs.

A related bug (fixed 2026-08-24, see `docs/ARCHITECTURE_DECISIONS.md`'s "NVS
rollback-refusal vs. legacy-partition migration" section): a refused
newer-than-firmware blob could still get silently overwritten by 8.1's
legacy-partition migration, because the migration decision couldn't tell
"refused" apart from "nothing was ever saved." Any new module that adds
both a version check AND a migration off another partition must read that
section before wiring the two together.

- [ ] **Migration path never verified on real hardware** — that a board with
      real saved zone/rules/profile/relay-cycle data actually carries it
      forward into `kiln_nvs`/`profiles_nvs` on first boot after this
      change, and that `zones_config_valid` reads `true` after migration and
      `false` on a genuinely unconfigured board.

### 8.3 Config wizard page: what is set up, what is not

DONE — `GET /readiness` + `GET /api/readiness` (`App/drivers/
readiness_http.{c,h}`), a pure read-only aggregator over 11 items (network,
thermo/zone mapping, relay assignment, control mode, guard limits,
calibration, profiles, autotune, hardware present, storage compatible), each
`ok`/`not_done`/`cannot_yet`/`deliberately_off`, ordered so a page doesn't
nag about a step that's blocked on an earlier one.

Two honest, documented gaps left as `not_done`/`ok`-only rather than
inventing a distinction the storage doesn't carry: **control mode** has no
"explicitly set" bit distinct from its zero-initialized default, and
**calibration**'s `cal_offset_c == 0` has no "deliberate zero" convention the
way `max_temp_c`/`cross_zone_max_delta_c` do. Closing either needs a new
persisted flag per field — deliberately not added (out of this pass's scope).

### 8.4 Network page: live status, mode switch, and saved networks

DONE — live status (mode, join state, RSSI, IP, mDNS name, AP client count)
on the same page as the mode switch; a bounded (8-entry) saved-network list
with a documented RSSI tie-break and Forget; `GET /networks` merges saved +
scanned into one view rather than two lists; forgetting the last saved
network is allowed (drops to AP mode, never blocked); stored passwords are
never returned by `wifi_prov_get_saved_networks()` (structurally absent from
its output type) — except the board's **own** AP identity, an explicit,
user-confirmed scoped exception, always shown pre-filled for editing.

- [ ] **Nothing in this subsection has been flashed/tested on real
      hardware.** In particular: a pre-8.4 single saved network migrates
      into `nets[0]` and still joins on boot; two saved networks and the
      board actually prefers the stronger one; forgetting the last saved
      network drops to AP mode without stranding the operator; the periodic
      30s rescan (`rescan_timer_cb`) rejoins a saved network coming back
      into range without waiting for a disconnect event; and moving the
      scan-based tie-break off the Wi-Fi driver's disconnect-event handler
      (onto that periodic timer instead) doesn't introduce a noticeably
      slower reconnect when the active network is just flapping.

### 8.5 Sequencing

Reference only, all four sub-sections shipped in the dependency order this
called for (8.2's versioning before 8.1's partition split; 8.1 before 8.4's
saved list; 8.3 last as a view over the other three).

---

## 9. Firmware updates — ESP OTA and relaying the Pico's image

Full design (interlocks, shared authentication): [`../CommonFW/docs/
UPDATE_PROTOCOL.md`](../CommonFW/docs/UPDATE_PROTOCOL.md). RP2040 half:
[`../SaftyFW/docs/BOOTLOADER.md`](../SaftyFW/docs/BOOTLOADER.md). Two things
make this more than a normal OTA feature: the partition table can only be
changed over a cable (**you cannot OTA your way into being OTA-capable**, so
the first flash of the new table is a one-time USB step); and the ESP is the
only thing authorising a Pico update, making this endpoint the safety
processor's attack surface too.

**Everything through 9.6a is built and either host-tested or `idf.py build`
clean** (mutual version compatibility, the 8/16MB partition table +
rollback, HMAC-challenge auth with lockout, interlocks that refuse an update
unless idle/cool/safety-link-healthy, streamed transfer for both processors
via a `pico_img` staging partition, the web page, and MCP tools). **No
physical ESP32-S3 or Pico exists in this environment — nothing in this
section has ever run against real hardware.** Section 9.7 below is
therefore the entire hardware-verification surface still owed, and every
other open item below is a real, separately-named gap rather than a
hardware caveat.

### 9.0 Mutual version compatibility (prerequisite)

DONE — `ANNOUNCE_VERSION` burst at boot/on `boot_id` change (now via the
shared `kilnlink_announce` codec), bidirectional `KILNLINK_MIN_COMPATIBLE`
check, a mismatch treated as a dead link, the GUI naming both versions and
which is older (always "update ESP first"), and an explicit `GET_FW_VERSION`
retried until answered. Full detail: `LINK_PROTOCOL.md` sec 4.

- [x] **Refuse to push a Pico image this build could not then talk to**
      (protocol-incompatible). DONE — closed by 9.5's matching item:
      `ota_pico_do_stage()` (`ota_http_pico.c`) refuses a staged image whose
      `link_protocol_version` differs with `409 Conflict` unless
      `X-Ota-Force-Version: 1` is sent.

### 9.1 Partition table

DONE — confirmed N16R8 (16MB flash/8MB PSRAM); `partitions.csv` carries
`otadata` + `ota_0`/`ota_1` (2048K each) + `pico_img` (896K, corrected up
from an originally-proposed 512K — too small for SaftyFW's 832K app slot),
all above `0x200000` where nothing else lives. Rollback enabled
(`CONFIG_BOOTLOADER_APP_ROLLBACK_ENABLE=y`). `idf.py build` clean, no
overlap/overflow.

- [x] **`esptool flash_id` never run** — CLOSED 2026-10-07: esptool is forbidden
      by policy (`docs/agent_rules/BENCH.md`; OpenOCD only) and the N16R8 part is
      known. (The buy-list and 3D-model records claiming 8MB/N8R8 were noted stale
      here; not re-verified in this pass.)
- [x] **Bootloader + partition table reflashed on the physical board** —
      2026-08-24 (the date this was directly observed; an earlier flash on
      2026-08-22 is likely but was not confirmed against this table), via
      `flash_firmware()`'s JTAG path (`tools/PcTools`):
      `bootloader.bin`@0x0, `partition-table.bin`@0x8000, `KilnCtrl.bin`@0x810000,
      each `program_esp ... verify`, reported "flashed and verified OK". Note
      the app offset: 0x810000 is `factory`'s offset in this table, so this
      path has never written an OTA slot (see 9.2's note on what that means
      for rollback confirmation).
- [x] **Pre-change partition table archived** — MOOT 2026-10-07: the table was
      redesigned (single-slot, `docs/OTA_SINGLE_SLOT_PLAN.md`) and flashed; there is
      no pre-OTA table to roll back to.
- [x] **One-time serial flash documented as a prerequisite step**, not a
      footnote. DONE — added a dedicated bullet to
      `firmware/KilnFW/docs/PROJECT_STATUS.md`'s "Current build/hardware
      configuration" section, naming the JTAG/serial requirement explicitly
      and pointing at `firmware/CommonFW/docs/UPDATE_PROTOCOL.md` §3, which
      already carried the underlying rationale but only as narrative prose,
      not a bring-up-checklist item.
- [x] **`nvs`/`wifi_nvs`/`kiln_nvs`/`profiles_nvs` archived with `esptool
      read_flash` before the new table is flashed** — MOOT 2026-10-07: the new
      table was flashed long ago, and esptool is forbidden by policy (OpenOCD
      only); the step can no longer be done as written. Use `backup_export` for a
      config backup.

### 9.1a PSRAM — enabled 2026-08-17

DONE. Originally decided off (four reasons: no framebuffer needed since the
ILI9488 driver streams to its own GRAM, determinism/stall risk, a new boot
failure mode, DMA-buffer audit cost); reversed once LVGL (section 10) needed
draw buffers — the named trigger this decision itself called out in advance.
`sdkconfig`: `CONFIG_SPIRAM=y`/`_MODE_OCT=y`/`_BOOT_INIT=y`. LVGL's draw
buffers and allocator, plus several bridge-task stacks, now live in PSRAM
(see `docs/BRINGUP_HAZARDS.md` for the internal-SRAM race this interacted
with). R8 (with PSRAM) is now a hard requirement on any board reorder — an
R2/no-PSRAM part would break the LCD memory plan.

- [ ] **Second, weaker trigger**: TLS on the web server, or many concurrent
      HTTP connections — measure the heap before assuming either needs more
      PSRAM use.
Standing rule (not a task): keep GPIO 33-37 unassigned -- they are consumed by
the R8 module's own PSRAM regardless of software config. No conflict today (board
uses 0-21, 38, 43, 44, 47, 48); keep it that way on any future pin assignment.

### 9.2 Rollback

DONE — `esp_ota_mark_app_valid_cancel_rollback()` runs from a background
task gated on NVS-readable + web-server-up + OTA-routes-up
(`boot_confirm_is_healthy()`, `App/drivers/persist/boot_guard.h`); a live
safety-link exchange was dropped from the bar 2026-08-22 (a board with no
RP2040 answering could otherwise never confirm, silently reverting every OTA
update). `CONFIG_BOOTLOADER_APP_ANTI_ROLLBACK` deliberately left off.

- [x] **Factory-boot false ERROR fixed, 2026-08-24** — every JTAG-flashed
      build boots from `factory` (see 9.1), and
      `esp_ota_mark_app_valid_cancel_rollback()` has nothing to cancel there;
      it reliably returned `ESP_FAIL`, logged as an ERROR every boot.
      `ota_rollback_confirm_task()` (`App/main.c`) now checks
      `esp_ota_get_running_partition()` and, via
      `boot_confirm_decide()` (`boot_guard.h`), skips that call on a factory
      boot with an explanatory INFO line instead — `boot_guard_mark_healthy()`
      still runs. OTA-slot boots are unchanged.
- [ ] **Still not exercised end-to-end by anything on this bench** (re-checked
      2026-10-07: no evidence in `docs/BENCH_TEST_LOG.md` or `logs/bench_test/`). The
      PENDING_VERIFY / rollback-cancel machinery has only run in host tests
      (`test_boot_guard.c`). Under the single-slot design
      (`docs/OTA_SINGLE_SLOT_PLAN.md`) a direct push into the running `app` slot is
      refused (OT-E01), so exercising it needs the recovery-image path
      (`recovery_enter` -> `recovery_apply_staged` -> `recovery_exit`); that apply
      has not been performed on the bench (the stage step only, BENCH_TEST_LOG).

### 9.3 Authentication — the AP password, not sent over the wire

DONE — single-use 30s-expiry challenge, HMAC-SHA256 proof of knowledge (PSA
Crypto API), constant-time comparison, lockout after 3 failures (doubling to
15 min, per-endpoint), every attempt logged with source IP, and only the
derived key (never the literal PSK) ever reaches the comparison.

- [x] **Stated user-visible on the OTA web page.** DONE — the prose exists
      in `UPDATE_PROTOCOL.md` §2, and `ota_page.html:135-139`'s note under the
      AP-password field already says the same thing in user-facing copy:
      "This proves you're on the network with the AP password -- it does not
      stop anyone else who also knows it...". Predates this classifier pass
      (present since the file's 2026-09-05 `drivers/` reorg move, `9f18ca5c`);
      this item was stale.
- [ ] **TLS — planned in `docs/UI_PLAN.md` §6, not authorized to build.**
      Adds confidentiality/integrity to the image transfer (today plaintext
      LAN); does not replace or weaken the HMAC scheme above, and is not
      image signing (that stays a separate, unplanned concern). Switching
      the shared `esp_http_server` instance to `httpd_ssl_start()` would
      cover every OTA route with no per-route change.

### 9.4 Interlocks

DONE — both update paths refused unless idle (no profile/autotune running,
no heater commanded, every zone below a configurable ceiling, safety link
healthy), refusals name the specific unmet precondition, and a single
in-RAM mutex refuses starting either update path while the other is in
progress. During a Pico update the safety-link-down alarm *text* is
suppressed (never the relay-on block itself).

### 9.5 Transfer

DONE — streamed `esp_ota_ops` POST handler for the ESP image (no full image
held in RAM), a `pico_img` staging partition + background relay task driving
the five `UPDATE_*` frames with gap-based retransmission (up to 10 rounds,
then always attempts `UPDATE_END` and lets the Pico's own CRC verification
arbitrate), whole-transfer socket timeouts, image magic/chip-ID validation
before `esp_ota_begin()`, `SAFETY_CMD_ANNOUNCE_REBOOT` sent before a routine
reboot so it doesn't trip the safety processor's S6b guard, the update
mutex's first real caller, an append-only (single-record) NVS update log,
and polled progress for both paths.

- [x] **Protocol-version mismatch between an uploaded Pico image and the
      running ESP is now proactively warned about with a second
      confirmation** before the relay starts. DONE — the uploaded image's own
      `KILNLINK_PROTOCOL_VERSION` was not previously captured anywhere on
      disk (the wire-frame `UPDATE_BEGIN` header the ESP builds always
      states the ESP's own version, never a value read out of the uploaded
      bytes), so this added a new `link_protocol_version` field to the
      `saftyfw_image_identity_t` build-identity record every SaftyFW slot
      image already carries (`firmware/CommonFW/include/kilnlink/saftyfw_image_identity.h`,
      `SAFTYFW_IMAGE_IDENTITY_RECORD_VERSION` bumped 1 -> 2, reusing the
      previously-unused `reserved` field so the record stays 60 bytes; a
      record_version 1 image correctly reads as "unknown", never a
      fabricated protocol 0). `ota_http_pico.c`'s manual-upload handler
      (`ota_pico_do_stage()`) now calls the existing
      `pico_image_source_describe()` scanner right after staging finishes
      and, if the staged image's `link_protocol_version` disagrees with this
      board's compiled `KILNLINK_PROTOCOL_VERSION`, refuses with
      `409 Conflict` and a JSON body naming both versions
      (`{"error":"protocol_version_mismatch","image_protocol_version":N,"esp_protocol_version":M}`)
      unless the request carries a new `X-Ota-Force-Version: 1` header
      (mirroring `ota_http.h`'s existing `X-Ota-Ack-No-Safety` pattern — a
      header, not a body field, since this route's body is the raw image).
      No new HTTP route was added. The Pico's own
      `UPDATE_STATUS_ERR_VERSION_INCOMPATIBLE` refusal is unchanged and still
      runs regardless — this is a strictly earlier, proactive warning on top
      of it. The boot-time auto-update path (`pico_auto_update_boot.c`)
      calls `ota_pico_relay_start()` directly and never reaches this
      handler, so it can never set the force header and is structurally
      unaffected. PC-side: `tools/PcTools/src/kilnctrl/ota_http_client.py`'s
      `push_pico_image()` gained a `force_version` parameter (default
      `False`) and raises a new typed `OtaPicoProtocolVersionMismatch` on the
      409; the `ota_update_pico` MCP tool surfaces the same. Host-tested:
      `firmware/CommonFW/test/test_saftyfw_image_identity.c` (new,
      CMake-registered) covers the record_version bump end to end, including
      that a record_version 1 image is rejected rather than misread; pytest
      covers the client/MCP surface
      (`tools/PcTools/tests/test_ota_http_client.py`) and the drift guard
      against the C header
      (`tools/PcTools/tests/test_pico_image_freshness.py`).
- [x] **`ota_record_t` has no image SHA-256 field** — flagged, not faked;
      would need hashing the stream as it passes through the transfer
      handler (mbedTLS/PSA is already linked for the HMAC path). DONE --
      `image_sha256_hex` is hashed via PSA as the transfer streams through
      (`ota_http_esp.c:207-342`, split out of what was then `ota_http.c`)
      and surfaced on `/api/ota/status` (`ota_http_esp.c:538`, likewise
      split out of `ota_http.c`).

### 9.6 Web page

DONE — `GET /ota` (`ota_page.html`), per-processor version/commit/build-date/
dirty-flag/active-inactive-slot (ESP side), interlock state shown before the
file picker (unauthenticated `GET /api/ota/interlock`, file pickers hidden
entirely until it reports idle), progress bars, and an ESP rollback button
(`POST /api/ota/esp/rollback`, its own HMAC context so a push-authorization
signature can never double as a rollback authorization).

- [x] **Pico build commit/dirty flag/build date are not retrievable.** DONE
      (found shipped, eighth audit pass, 2026-09-04): `safety_link.h` now
      carries `peer_build_known`/`peer_build_dirty`/`peer_build_commit[64]`/
      `peer_build_commit_len`/`peer_build_datetime[32]`/`peer_build_datetime_len`
      (`safety_link.h:1145-1155`), populated by the FW_VERSION parse and read
      via `safety_link_get_peer_build_status()` (`safety_link.h:1349`,
      `safety_link.c:832-841`). Surfaced through `dashboard_http.c`'s
      `safety_build_*` fields (`GET /api/status`) and rendered on the OTA
      page's `renderPicoInfo()` (`ota_page.html:490-494`).
- [x] **Pico rollback button is a disabled placeholder** ("not yet
      available") — no HTTP route exists; a Pico rollback trigger is
      expected to go over the safety UART link (`SAFETY_CMD_ROLLBACK`, 0x17,
      already built on the send side per `safety_link_send_rollback()`), not
      HTTP. DONE -- the button is live and wired (`ota_page.html:168`,
      `:597-624`), POSTing `/api/ota/pico/rollback` with MAC-authenticated
      request/poll-for-status handling.

### 9.6a MCP tools (`tools/PcTools`)

DONE — `ota_get_challenge`/`ota_update_esp`/`ota_update_pico`/`ota_status`/
`ota_rollback_esp` all wrapped as `kilnctrl` MCP tools (reachable via
`kiln_call`), unit-tested
against mocked HTTP. No physical board has ever answered a real request from
these tools. `image SHA-256` is unbuilt (same gap as 9.5's `ota_record_t`
note).

### 9.7 Verification

Superseded 2026-10-07 by the scripted OT matrix in
`tools/PcTools/src/kilnctrl/bench_test/cases_ota.py`
(`docs/BENCH_TEST_SYSTEM_PLAN.md` section 3.4; run with `bench_test_run(suite="ota")`
or `ota_matrix_run`). Execution status, from `logs/bench_test/*ota*` (gitignored) and
`docs/BENCH_TEST_LOG.md`, not from the matrix existing:

- [x] Corrupt image rejected (OT-E03 bad CRC, OT-E04 truncated, OT-E05 wrong build):
      real-board PASS for the ESP push path, run `20261003T223938Z_ota_ot_410c346c_rerun`
      (with OT-E01 self-push 409, OT-E09 no-credential, OT-E12 otadata state). Pico-side
      corrupt-image refusal is not covered by an OT case.
- [x] Update attempted while firing/autotune refused (OT-E07/OT-E08): real-board PASS,
      run `20261005T160721Z_ota_bench20261005` (an earlier run `20261004T000619Z`
      SKIPped both because no state was running).
- [x] Dual reflash (OT-B01): PASS on hardware 2026-10-03, with the caveat that
      `sw_reset_esp` does not latch S6a, so the "expected S6a trip" branch has not
      been observed via this path.
- [ ] Power pulled mid-transfer, both processors (OT-E06): attended case, never
      executed to a verdict. Needs an operator.
- [ ] An image that boots but fails bring-up is rolled back with no intervention:
      no OT case exists for it; still open.
- [ ] Recovery from a deliberately bricked Pico over SWD: blocked on the missing
      CMSIS-DAP probe (2026-10-03, see the Pico debug-probe note in
      `docs/BENCH_TEST_LOG.md`).
- [x] ~~Wrong password: refused, locked out, logged~~ MOOT 2026-10-07: the AP-password
      HMAC scheme was retired 2026-09-29 ("Retire; open when login off",
      `docs/WEB_AUTH_PLAN.md` item 2b); OT-E09/E10 cover the web-auth gate instead.

## 10. LCD touchscreen GUI (Klipper-style screen)

The LCD (ILI9488, physically connected) has its own touchscreen UI, kept in
sync with the web dashboard rather than duplicating/diverging from it (see
10.5). Usability/no-scroll budget audit and fix queue: `docs/UI_PLAN.md`.

### 10.1 Generic screen/page/widget framework

DONE — LVGL chosen and owns the ILI9488 outright (replacing the old
UART-remote-drawn `DISPLAY_CMD_*` path; this was an explicit user decision
once two independent draw-call owners proved to be an unresolvable race).
`App/drivers/ui/kiln_ui.c`/`.h` is the page registry/switcher; every page is its
own `ui_page_<name>.c`/`.h` pair, never inlined into `kiln_ui.c`. Fixed a real
bug in the process: a touch waking the screen from idle previously set a flag
with nothing to repaint it — `lvgl_port.c`'s flush callback now forces a
redraw on the wake edge.

- [x] **The twelve stale `display_*` MCP tools were deleted** (ROADMAP.md:1140,
      1071-1083). This entry was stale — see `DISPLAY_ST7796_PLAN.md` §0 and
      §14.
- [x] **`uart_bridge.c`'s `display_bridge_task`/`uart_bridge_start_display_task()`
      were deleted 2026-08-27 (`ddbd0248`)** — confirmed dead code first
      (`main.c` never called `uart_bridge_start_display_task()`; LVGL owns the
      panel outright), then removed along with its `xTaskCreatePinnedToCore()`
      call site, header declaration, and its stack-margin registration entry.
      `DISPLAY_CMD_*`/`UART_TASK_ID_DISPLAY` stay defined in `uart_task_ids.h`
      as wire-protocol constants only — kilnctrl's `gui.py`/`actions.py`
      Display panel still speaks them, even though nothing on the firmware
      side answers any more. A later pass (2026-09-17, re-verified against
      `origin/main`) confirmed no trace of the task, its constants, or a
      registration entry remains anywhere in `firmware/`; `ARCHITECTURE.md`,
      `ARCHITECTURE_DECISIONS.md`, and `UART_PROTOCOL.md` already recorded the
      same removal and needed no further edit.
- [ ] Decide the color/asset story once the visual style (10.2) is picked —
      LVGL widgets are themeable, so this is a theme/style pass on stock
      widgets, not custom-drawn ones.
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

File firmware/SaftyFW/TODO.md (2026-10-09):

# TODO — Safety Processor Firmware

> **Status:** planning · **Last reviewed:** 2026-08-22
> **Keep this file current.** Tick items as they land, and keep "built" and
> "verified on hardware" distinct — `firmware/KilnFW/docs/PROJECT_STATUS.md` is the model
> for that discipline. Finished items are removed from this file (moved into
> the relevant `docs/*.md` if the reasoning is worth keeping, deleted if it was
> only working notes) rather than left here as a completed marker — see this
> repo's plan-doc convention.

Top-level ordering across both processors lives in [`../../ROADMAP.md`](../../ROADMAP.md);
this file owns the safety-processor detail. Phases here map to roadmap milestones
M0 and M2–M6.

Cross-references `docs/SAFETY_MODEL.md` (what trips and why),
`../CommonFW/docs/LINK_PROTOCOL.md` (the wire, both ends), `docs/HARDWARE.md` (the traced
board), `docs/CURRENT_SENSE.md` (the analog front end),
`docs/THERMOCOUPLE.md` (the sensor and its type), `docs/CONFIG_REFERENCE.md`
(every tunable) and `docs/GUARD_TEST_MATRIX.md` (how each guard is proven)
throughout.

---

## 2026-08-28 -- the elements are connected, and S1 is not armed

**THE KILN'S HEATING ELEMENTS ARE NOW PHYSICALLY CONNECTED to the main board.**
This processor's guards stopped being a bench exercise today.

**S1 is disabled on the live board.** `abs_max_temp_c` reads
`set: true, value: 0` and 0 there means never trip, so the only temperature
ceiling in force is `KilnFW`'s guard 5 -- running on the processor that
commands the heat, which is the arrangement this whole firmware exists to not
depend on. `commissioned` reports `false`. Note the reporting trap that hid
this from the coordinator for several hours: `KilnFW`'s `/api/readiness` says
"all 58 safety parameters have values", and a zero IS a value. Setting a
Pico-side ceiling (90 C was proposed, deliberately above the fixture's 80 C so
the primary acts first) is offered and awaiting the owner's number.

**The 80 C fixture cap is a TEST THRESHOLD.** Phase 9's "confirm no test
threshold was left in place" now has a concrete instance to check: `max_temp_c`
= 80 on all three KilnFW zones, and whatever `abs_max_temp_c` ends up as here.
Both are properties of the bench fixture, not of any kiln.

**Consequence of today's S9 change, restated because the bench changed under
it:** S9's unclearable `trip_ineffective` escalation now requires commissioned
current sensing, because an uncommissioned CT chain reads the op-amp offset
floor as permanent current and would brick the board. No CT is fitted, so **a
genuinely welded contactor raises a warning and nothing more.** That was an
acceptable trade while nothing could get warm. It is a real gap now, and
commissioning the CT channels is what closes it.

**UPDATE 2026-09-04, read live from the board (`GET /api/safety/commissioning`
while `fuzzy_ab_20260904d` was firing):** `abs_max_temp_c` is now `set: true,
value: 80`, and `commissioned` reports `true` — S1 is armed at the fixture's
80 C cap. The Pico-side ceiling this section says was "awaiting the owner's
number" has been supplied and committed; the "S1 is disabled"/"only
KilnFW's guard 5 is in force" state described above is no longer current. CT
channels (`ct_installed`, `ct_cal[*].calibrated`) remain unset/false, so the
S9 welded-contactor gap described in the paragraph above is still real. No
`fields_set`/sentinel-value contradiction remains for `abs_max_temp_c` either
(80 is not the 0-sentinel), so the "Secondary finding" further below in this
file is also resolved and can be treated as historical.

---

## Audit 2026-08-27 — open items

A six-agent read-only audit of both firmwares. Fixed and committed already:
the dead `s_guard_cfg` (S1 unreachable at any temperature), the
`tc_placement_valid` gate (S2/S10 armed on uncommissioned boards).

**Swept 2026-09-02: every item below except the last was already fixed by the
2026-08-27 audit pass and this checklist had simply never been ticked** — each
was re-verified against the current source before being closed here, not
assumed from the commit log:

- [x] ~~`safety_guards_try_clear()` grants a full re-arm window against a
      still-present hazard.~~ Fixed. `guard_condition_still_immediate()`
      (`src/safety_guards.c:149`) now covers S2/S3/S5/S11/S12/S13, each
      recomputed from the current tick's `in`/`state` rather than trusting an
      accumulator `safety_guards_clear()` is about to zero.
- [x] ~~`TRIP_INEFFECTIVE` (S9, welded contactor) is clearable.~~ Fixed on both
      sides: `safety_guards_try_clear()` refuses unconditionally whenever
      `state->trip_ineffective` is set, before either of the checks above run
      (`safety_guards.c:228`), and `link_frame_decide_clear_trip()`
      (`src/tasks/link_frame.c:223`) refuses `SAFETY_TRIP_INEFFECTIVE` at the
      wire layer too, so the refusal is visible with a reason before the pure
      guard function is even reached.
- [x] ~~A trip during GRACE, once cleared, jumps straight to ARMED.~~ Fixed:
      `relay_clear_trip_transition()` (`src/tasks/relay_grace.c:23`) returns to
      GRACE when `elapsed_ticks < grace_ticks`, matching `relay_grace_tick()`'s
      own boundary, and only reaches ARMED when the grace window had already
      elapsed by the same instant a normal boot would have crossed it.
- [x] ~~A dropped `relay_owner_command_trip()` silently fails to open K4.~~
      Fixed: `relay_trip_command_still_owed()` /
      `relay_clear_command_still_owed()` (`src/tasks/relay_grace.c:40/48`) are
      wired into `safety_core.c`'s queue-drain loop (lines ~1176/1311) and
      retry the send until it succeeds, with the trip direction always winning
      a race against a superseding clear.
- [x] ~~Guard windows count nominal ticks, not wall-clock.~~ Fixed:
      `tick_dt_compute_s()` (`src/tasks/tick_timing.h`) measures real elapsed time
      from successive `now_ms` deltas, clamped, and falls back to the nominal
      constant only when `clock_health` reports the clock stalled
      (`src/tasks/safety_core.c:685`).
- [x] ~~Consumers do not age-check `thermo`/`current` snapshots.~~ Fixed:
      `safety_core.c:737` and `:899` gate both `tc_valid`/`current_valid` on
      `snapshot_is_fresh(now_ms, ...timestamp_ms, ..._MAX_AGE_MS)` in addition
      to the clock-health check, same audit pass as the `dt_s` fix above.
- [x] **S13's producer does not exist.** ~~`sample_counter_advancing` is
      hardcoded false.~~ Fixed: `context_borrowed_sample_counter_advancing()`
      (`src/snapshots.h`, host-tested in `test/test_snapshots.c`) compares the
      commissioned `borrowed_zone_index` zone's context-frame `sample_counter`
      against the last tick's, called from `safety_core_build_input()`
      (`src/tasks/safety_core.c`). `tc_source` may now be commissioned to
      BORROWED_ZONE/BOTH — see `SAFETY_MODEL.md`'s guard table.
- [x] ~~Config record field ranges are validated on commit but not on load.~~
      Fixed: `config_store_unpack_ex()` (`src/config_store.c:556`) calls
      `config_params_validate_ranges()` at load time too, and a structurally
      valid but range-refused record falls back to
      `config_store_default()` with `calibration_missing`/
      `config_store_is_config_rejected()` reporting why, not just booting
      unvalidated onto the guards.
- [x] ~~`config_store_get_config_version()` truncates `seq` to 8 bits.~~ Fixed:
      `config_store_seq_to_version()` (`src/config_store.c:942`) maps every
      `seq >= 1` into `[1, 255]` via `(seq - 1u) % 255u + 1u`, deliberately
      excluding 0 from the wrapped range (0 is reserved for the one real
      "never committed" case) instead of the old `seq & 0xFF` that let seq 256
      alias seq 0 and read as "no valid config".
- [x] ~~`config_store_write()` erases the whole sector then programs.~~ Fixed:
      `config_store_flash.c` already ping-pongs across the two slots in the
      sector (`s_cached_slot`, `config_store_next_write_needs_erase()`,
      `needs_erase` only true when both slots are full) rather than erasing on
      every commit.
- [x] ~~Only one trip reason is ever retained; `ARCHITECTURE.md` §9 promises a
      bitmask.~~ Doc corrected, not code changed — `ARCHITECTURE.md:539` now
      states plainly that `trip_mask` is a single latched reason, wire-encoded
      as one bit for backward compatibility, and that `trip_reason` is the
      authoritative field. Re-verified 2026-09-02: still accurate.
- [x] ~~`SAFETY_MODEL.md` §6 lists an E-stop assert/release cycle as a clear
      path.~~ Doc corrected, not code changed — `SAFETY_MODEL.md:882-908` now
      states explicitly that no such path exists, that releasing E-stop is
      only a *precondition* S7's `CLEAR_TRIP` recheck must see satisfied, and
      that `CLEAR_TRIP` must still be sent afterward. Re-verified 2026-09-02:
      still accurate, and matches the code (`safety_guards_try_clear()`'s only
      caller is `link_task.c`'s `CLEAR_TRIP` handler).
- [ ] **`watchdog_enable(..., pause_on_debug = true)`** with a probe
      permanently attached means a core halted in a fault state is never reset,
      disabling the documented fail-safe reboot on every bench board. GPIO6
      stays low through a halt so this is not an immediate heat-on hazard.
      Verify on the bench, then decide deliberately.

**Hardware-gated, repo-wide, historical**: the ESP32<->RP2040 isolated link
went unproven for a long time — `link_status` reported `frames_received: 0`
and the Pico console emitted zero bytes. The cause turned out to be the
TCMT1109 optocoupler pair's bandwidth, not the pin map or firmware: at 115200
baud zero frames were ever received. Walking the baud rate down settled on
9600, which both firmwares then hardcoded, and the link has run end to end on
the bench (2026-08-23) — see `docs/HARDWARE.md` §1 for the measurement. That
optocoupler pair was replaced by a non-inverting digital isolator (U6, an
ADuM1201WT) on 2026-08-25; the 9600 figure was a property of the retired
parts, not of either firmware, and the baud sweep is now complete — see
`KILNCTL_SAFETY_BAUD_RATE` in `KilnFW/App/drivers/Kconfig` for the committed
value. Items below marked hardware-gated may still be open for their own
reasons; the link itself is no longer the blocker.

---

## Phase 0 — Blockers (do these first, in this order)

- [x] **0.0 Pin test — done 2026-08-23, electrically.** Coordinated two-board
      GPIO drive/read (`docs/HARDWARE.md` §1) settled it: **ESP GPIO5 = TX,
      ESP GPIO4 = RX**, both data directions and the fault line inverting as
      predicted, cross-checked at register level over JTAG/SWD. The pull-down
      variant of this test is no longer worth running: it reads R15's position,
      and R15 was itself wired to the wrong net until 2026-08-22 — which is how
      the schematic-derived map came out inverted twice. Drive and read across
      the barrier instead. What was blocking the electrical half was a
      `gpio_probe` task stack overflow in `KilnFW` (3072 bytes, overflowed on
      its first command), fixed the same day.
- [ ] **0.5a Fit a 3-pin DEBUG header and bring GP16/GP17 out** before A1 is
      soldered down — both are far cheaper at build time than after.
      `docs/HARDWARE.md` §7b.
- [ ] **0.5b Consider a RUN (pin 30) reset wire** to the probe or a button while
      the board is still open. RUN is currently unconnected; OpenOCD's SWD reset
      is sufficient without it.
- [ ] **0.7 Confirm the K4 → line-contactor interlock topology** and which J10
      pin is NO vs NC. `docs/HARDWARE.md` §3. **This is a system-wiring decision,
      not a firmware one, and it must be settled before any bench trip test.**
- [x] **0.8 Confirm the E-stop is wired normally-closed** — closed 2026-09-10,
      owner decision: pole 1 stays permanently unwired on this fixture; the
      requirement is that the software-visible pole (GPIO9, S7) be read,
      debounced, tripped and relay-de-energized, which it is, pinned by
      `firmware/SaftyFW/test/test_estop_deenergizes_relay.c` and
      bench-verified (`estop_verified`). See ROADMAP's E-stop row and
      `firmware/SaftyFW/docs/HARDWARE.md` §5.

## Phase 1 — `CommonFW`, before either firmware uses it

The link contract is shared code, implemented once. See
[`../CommonFW/README.md`](../CommonFW/README.md) for the full checklist; the
gating items are:

- [x] **Won't do** — Shared ids split out of `uart_task_ids.h` into a
      `kilnlink_ids.h`; PC-link ids left behind. Investigated 2026-08-24: the
      `SAFETY_CMD_*` values in `uart_task_ids.h` that match a `KILNLINK_*_CMD`
      are deliberate literal mirrors, not accidental drift — several double
      as real PC→ESP dispatch values in `uart_bridge.c`, and the rest exist
      only so `uart_task_ids.h` stays the one place every subcommand on this
      wire is enumerated (its own doc comments say so explicitly). This
      firmware's own `src/tasks/link_frame.h` makes the identical choice for
      the identical reason (`LINK_FRAME_CLEAR_TRIP_CMD` etc., redeclared
      "rather than pulling the kilnlink codec header into this file's own
      namespace," even though `link_task.c` already includes those codec
      headers directly) — an established, repo-wide convention this item
      would have reversed for no fixed drift. See
      `../CommonFW/README.md`'s matching Contract entry for the full
      evidence.
- [x] `kilnlink` codecs — all pure and bounds-checked, host-tested, consumed
      by `pc_tools` as the third implementation. Every wire command through
      `0x1A` (`SET_CT_CAL`/`GET_CT_CAL`/`CT_CAL`) now has a codec in
      `firmware/CommonFW/src/`, including `kilnlink_ceiling.c` (SET_FIRING_CEILING)
      and `kilnlink_set_clock.c` (SET_CLOCK) — **this file previously claimed
      those two were "not yet coded"; that was stale.** The SaftyFW-side
      *consumer* wiring this entry used to list as still-open is also done
      and was likewise stale: `link_task_handle_set_firing_ceiling()` and
      `link_task_handle_set_clock()` both exist and are dispatched, with the
      `min()` ceiling clamp living in `safety_guards.c` and covered by
      property tests sweeping `1e30`/`NaN`/`±Inf` (verified 2026-08-22).
- [x] `KilnFW`'s `uart_protocol.c` delegating framing/CRC, proven byte-identical
      to the pre-refactor output. **Re-swept 2026-09-03: already shipped.**
      `firmware/hwAbstraction/esp/uart/uart_protocol.c`'s `frame_and_send()`
      (lines 97-113) calls `kilnlink_stuff()` directly, and the CRC sites
      (lines 165, 204, 740, 847) call `kilnlink_crc16_ccitt_false()`
      directly. The thin wrapper was deliberately removed 2026-08-27 so its
      own name would stop tripping the isolation grep, proven byte-identical
      in `App/test/test_uart_protocol_link_delegate.c` before removal.
- [x] CI grep: no CRC or byte-stuffing implementation outside `CommonFW` —
      2026-08-22, `tools/check_link_impl_isolation.ps1`. Standalone (matching
      `check_isolation.ps1`'s convention), not build-wired. **Re-run
      2026-09-03: now green.** Output: "Link implementation isolation check
      passed: no CRC/byte-stuffing implementation found outside
      firmware/CommonFW." The "real hits" this entry used to report were the
      pre-delegation `uart_protocol.c`, fixed by the item above — this is
      the check working, not a false positive resolving itself.

## Phase 2 — Skeleton

Built and build-verified under the real toolchain (arm-none-eabi-gcc 14.2.1 /
pico-sdk 2.1.1 / FreeRTOS-Kernel RP2040 SMP, Ninja). **Never flashed or run on
real hardware** — no RP2040 attached to any machine this has been built on.

- [ ] Blink-equivalent proof of life over SWD/RTT, and the physical heartbeat
      LED's toggle logic — **neither verified**; no RP2040/debug probe attached
      to any build machine.
- [x] Runtime log-level command over the link. ⚠️ **Blocked on a decision, not
      on code**: `log_task_set_level()`/`_get_level()` exist and work
      internally, but `CommonFW` allocates **no wire command id** for this —
      grepped end to end 2026-08-22 for `log_level`/`LOG_LEVEL`/`SET_LOG`,
      nothing. Minting one is a wire-contract change (`LINK_PROTOCOL.md` plus
      both firmwares plus `pc_tools`), so it is the owner's call rather than
      something `link_task.c` can decide unilaterally. Low risk when it
      happens — additive, and an older peer ignores an unknown id — with
      `0x1B` the next free id. DONE — `SAFETY_CMD_SET_LOG_LEVEL` (0x1B) is
      now a real wire command (`kilnlink_set_log_level.h`), handled by
      `link_task.c`'s `link_task_handle_set_log_level()`
      (`KILNLINK_SET_LOG_LEVEL_CMD` case, ~line 2179).
- [ ] RTT as `SaftyFW`'s secondary log transport — needs the debug probe wiring
      on the bench.

## Phase 3 — Thermocouple

- [~] **Choose `tc_type` deliberately, per sensor** — type K is marginal above
      ~1150 °C and green-rots *low* in reduction; type S/R suits a
      chamber-mounted sensor on a cone-10 kiln (`docs/THERMOCOUPLE.md` §2).
      Owner decision 2026-08-22: **this is not a compile-time choice at all.**
      It is commissioned from the ESP web GUI along with the rest of the
      safety parameter surface, and persists on the safety processor —
      see [`docs/COMMISSIONING.md`](docs/COMMISSIONING.md) for the mechanism.
      Until a real record is written every board still resolves to type K via
      the safe-default path, which is not a claim that K is correct here.
- [x] **Per-type plausibility ranges** — done 2026-08-24,
      `src/max31856_tc_range_policy.c`, wired in `thermo_task.c` (feeds S5's
      existing sensor-invalid path; no new trip). Ranges are datasheet Table 1
      (`firmware/KilnFW/Datasheets/MAX31856.pdf` p.12), inclusive both ends;
      host-tested for all 8 real types, both boundaries, NaN, and the
      unrecognised/voltage-mode-type case (`test/test_max31856_tc_range_policy.c`).
      Applied unconditionally, including on a never-commissioned (default
      Type K) board — deliberate, argued in the policy header and
      `docs/THERMOCOUPLE.md`'s §2 update, not gated on a "commissioned"
      flag (tc_type has none — see `config_store.h`'s own doc comment on
      that field, unchanged by this pass). Distinct from, and does not
      replace, the MAX31856's own unmaskable `TCRANGE` fault bit already
      folded into S5: this check is anchored to config_store's belief, so it
      additionally catches config_store and the part's actual CR1 register
      going out of sync (e.g. a failed `max31856_configure()` write). Does
      **not** solve `docs/THERMOCOUPLE.md`'s §2 wrong-sensor-physically-
      fitted case (a real Type-S junction read through Type-K's LUT still
      lands inside K's own range) — that section's existing "nothing in the
      electronics can detect this" stands, and still needs the commissioning
      soak-test check it already lists. Not yet hardware-verified.
- [ ] Bench: read ambient with the thermocouple attached; confirm open-circuit
      reports `THERMO_FAULT_OPEN` rather than a plausible number. Phase 9
      commissioning work; no hardware attached to do it yet.
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

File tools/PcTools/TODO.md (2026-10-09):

# PcTools — one GUI and MCP server for both processors

> **Status:** planning · **Last reviewed:** 2026-09-02
> **Keep this file current.** If a tool, page or transport changes, update it in
> the same commit. If it disagrees with the code, **the code wins.** Finished
> items are removed from this file rather than left as a completed marker —
> see this repo's plan-doc convention. Checklist at the bottom.

The code lives at `tools/PcTools/` (`docs/REPO_LAYOUT.md`) and serves both
processors — `safety.py`/`probe.py`/`pico_gpio_probe.py`/`debug_probe.py` talk
to the RP2040 side, everything else to the ESP. This document tracks the
remaining "serve both processors evenly" work and the capabilities that make
the tool usable by an agent rather than only by a human at a Tk window.

The Python package keeps the name `kilnctrl`: it is the system's name, not the
main board's.
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

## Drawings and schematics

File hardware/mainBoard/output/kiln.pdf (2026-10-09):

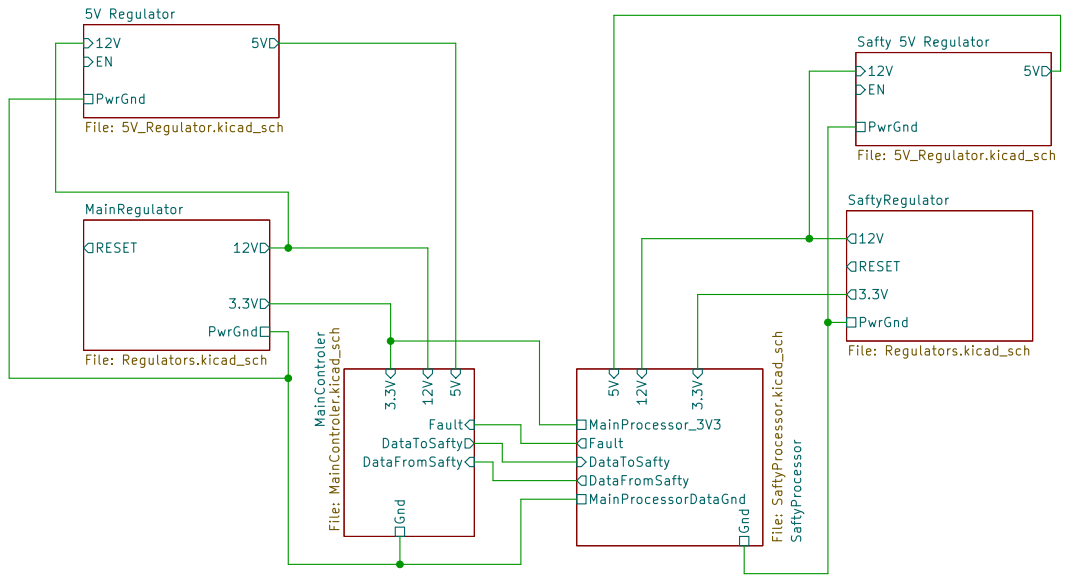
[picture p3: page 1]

PwrGnd 5V Regulator File: 5V_Regulator.kicad_sch 3.3V 12V PwrGnd RESET MainRegulator File: Regulators.kicad_sch

PwrGnd Safty 5V Regulator File: 5V_Regulator.kicad_sch

Size: A | Rev:
KiCad E.D.A. 10.0.4 | Id: 1/15

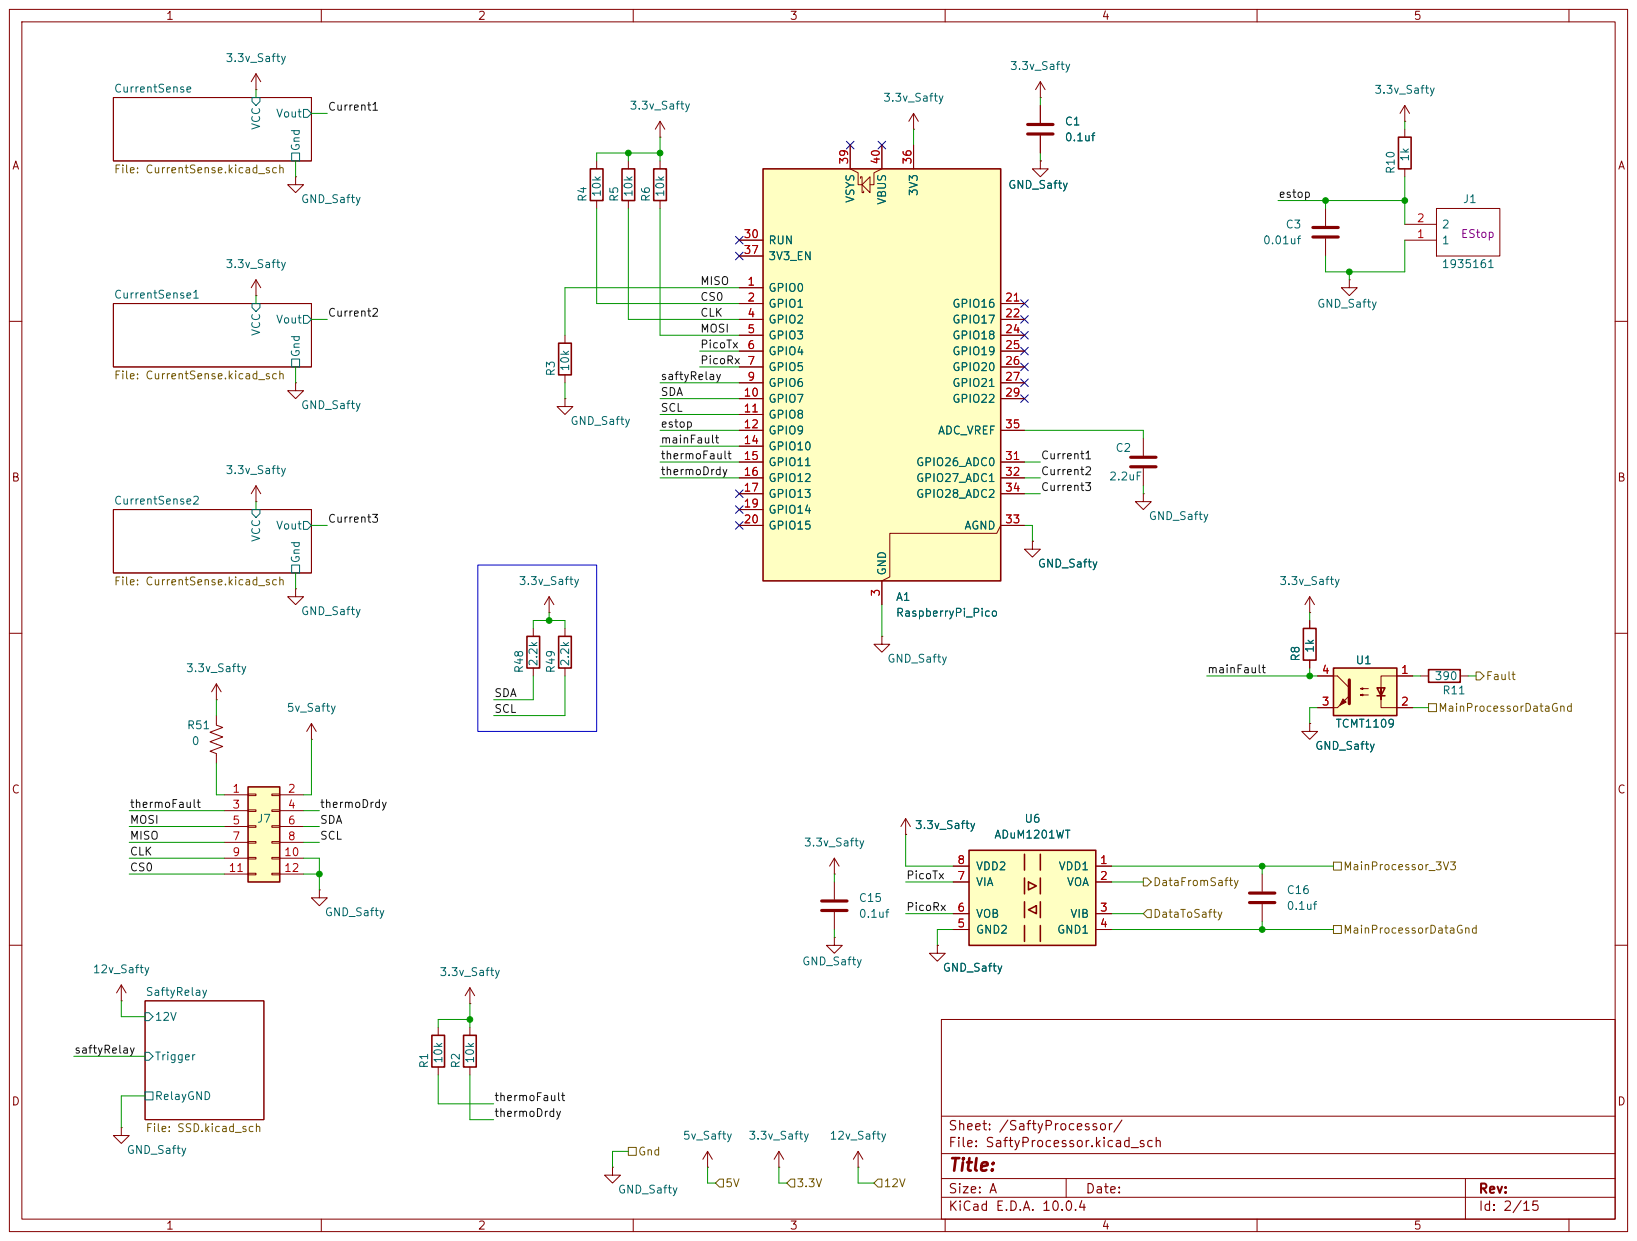
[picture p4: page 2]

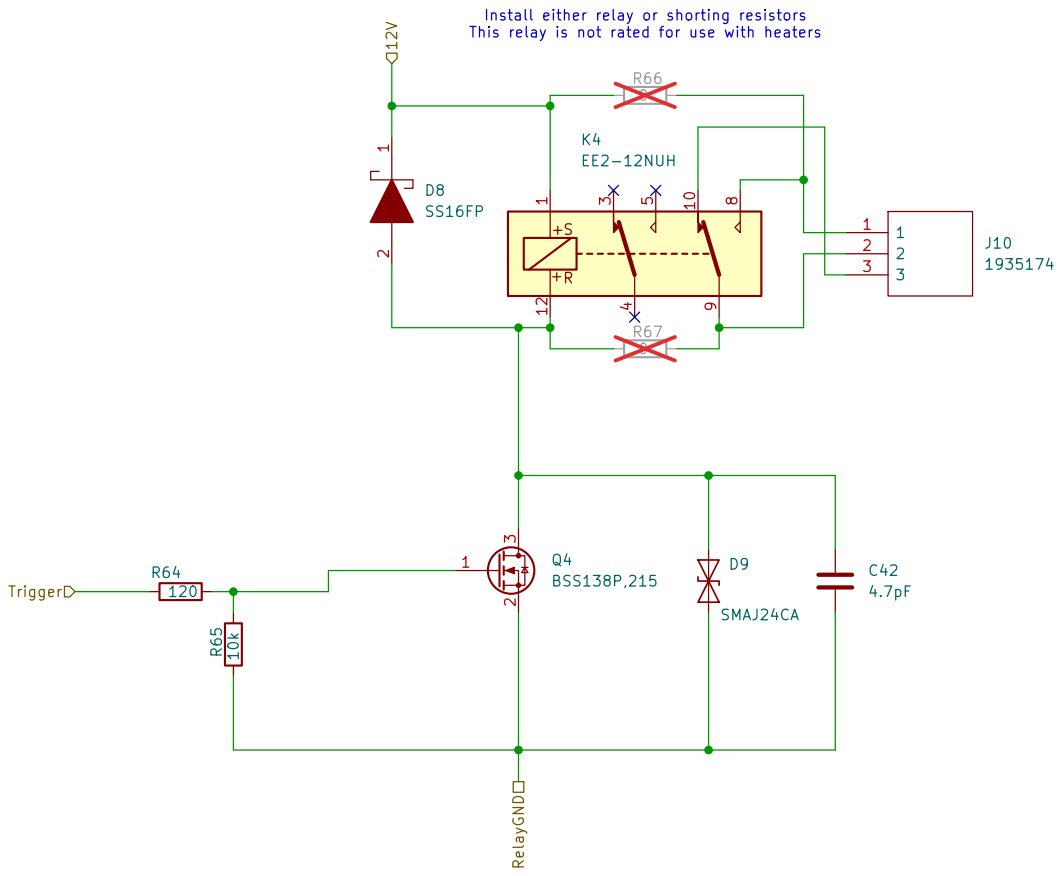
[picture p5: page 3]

Install either relay or shorting resistors
This relay is not rated for use with heaters

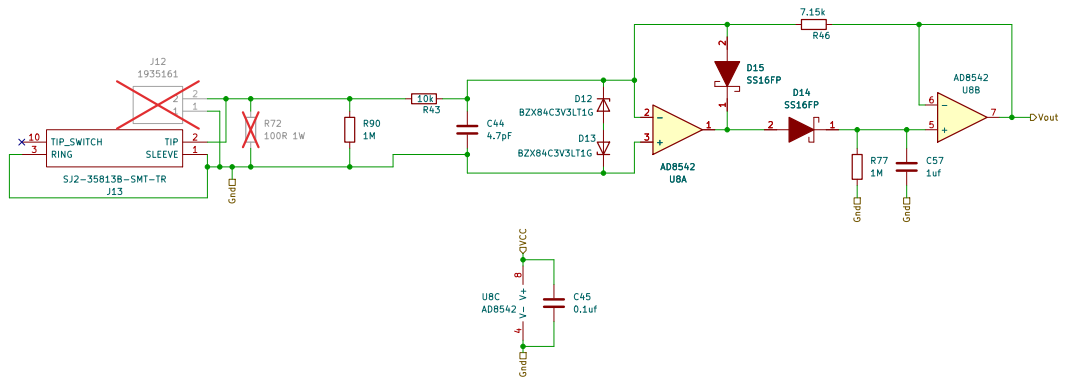
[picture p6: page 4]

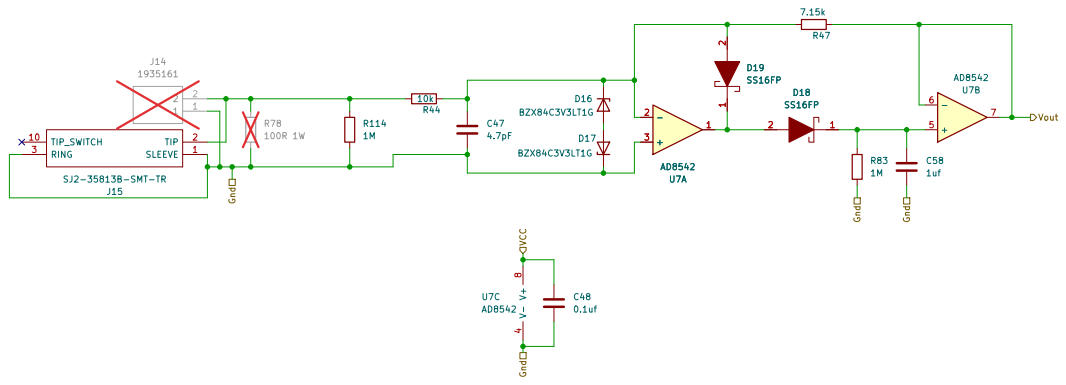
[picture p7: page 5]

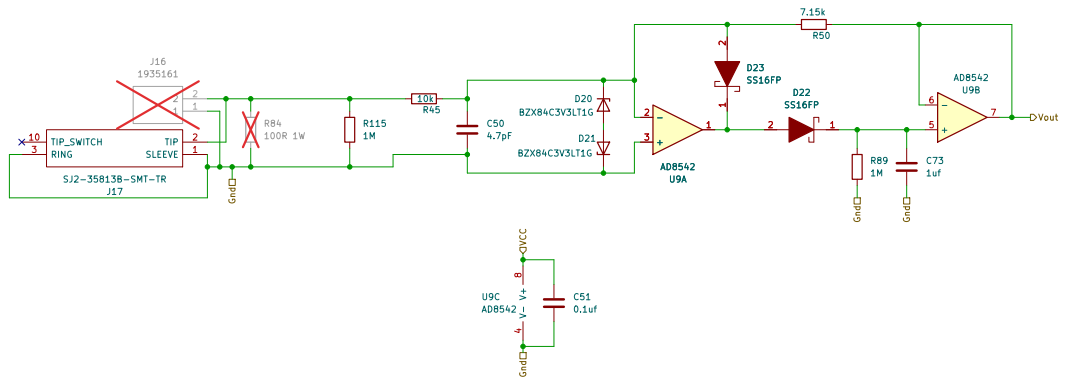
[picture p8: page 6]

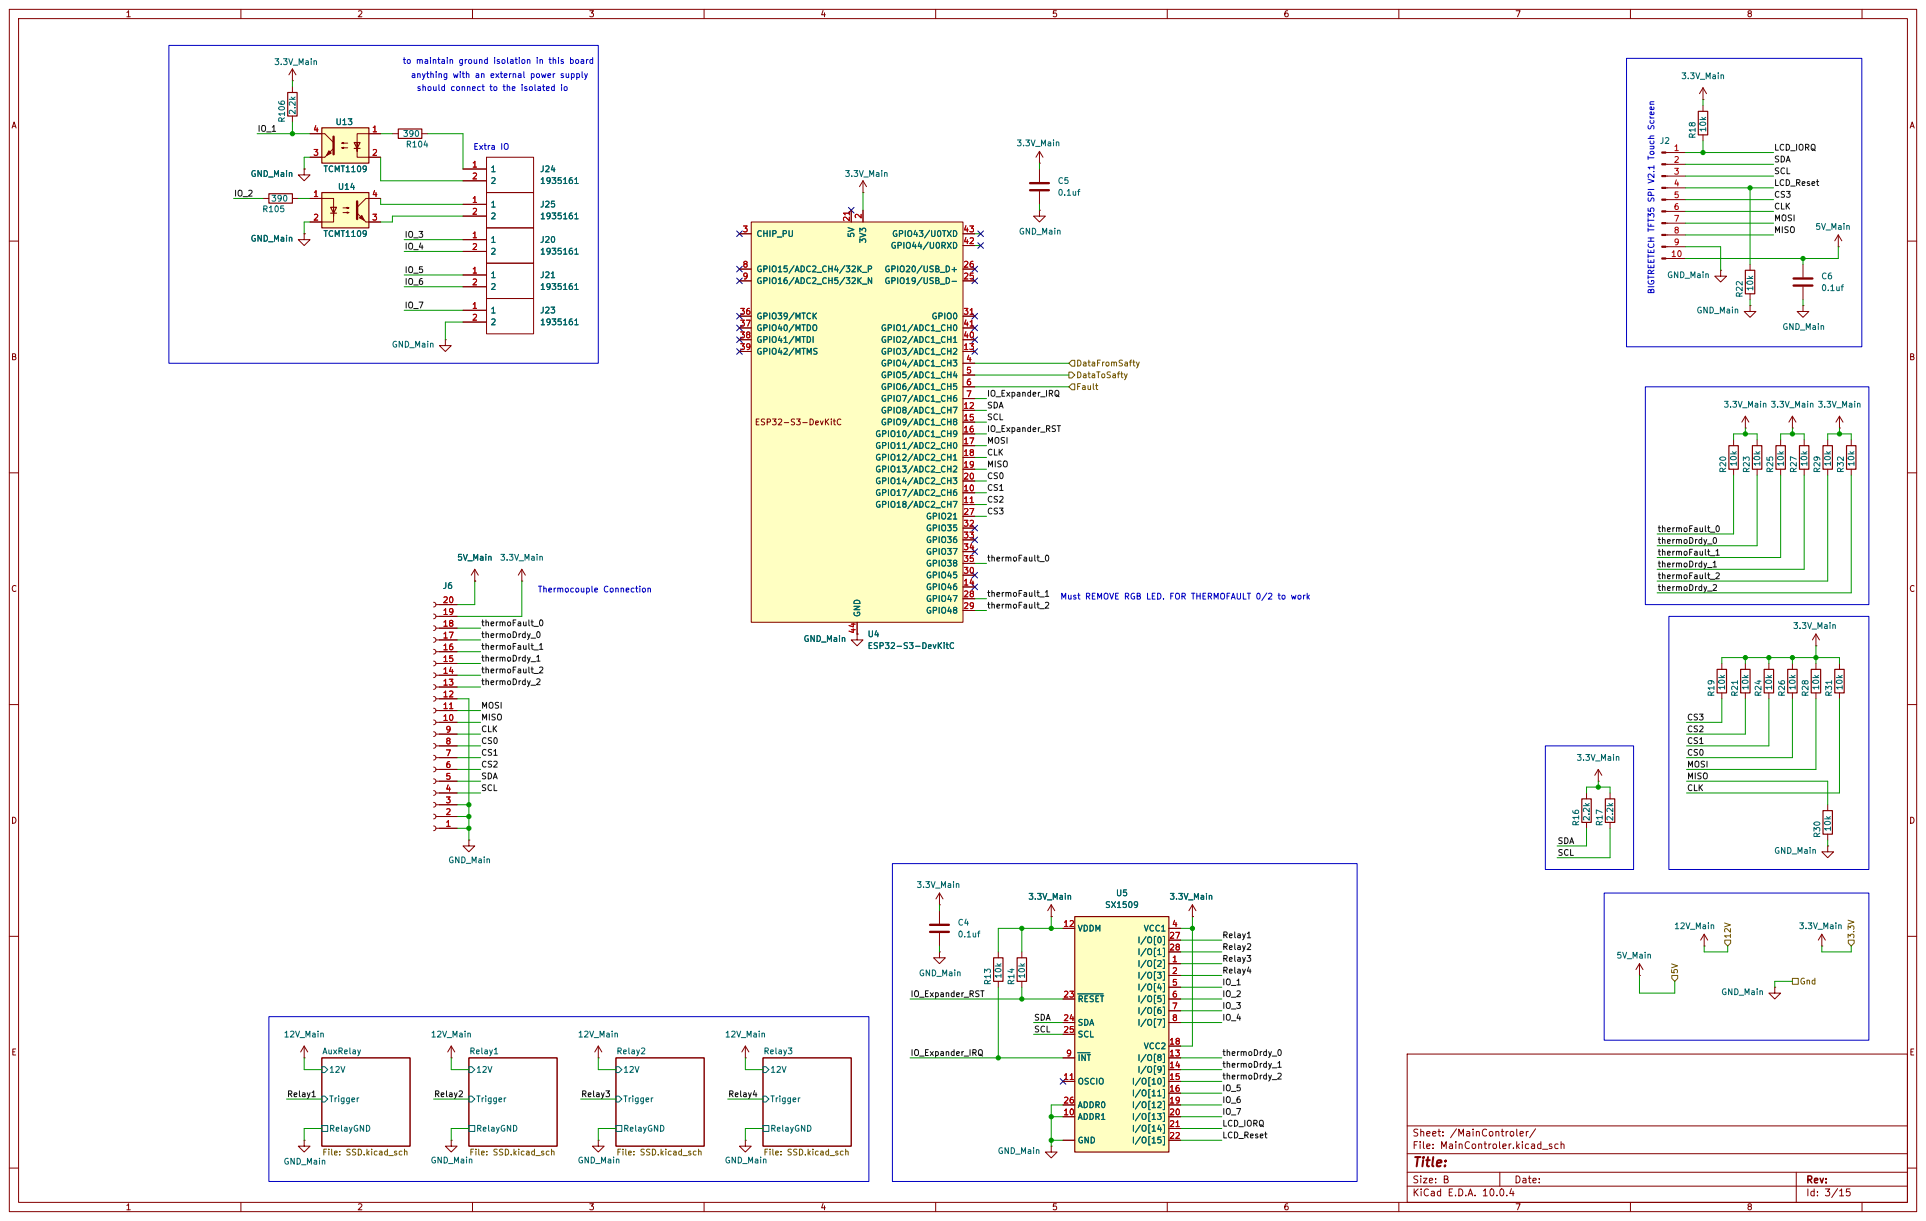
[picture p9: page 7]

to maintain ground isolation in this board

should connect to the isolated io

IO_Expander_IRQ
CLK MOSI SDA SCL

3.3V_Main

Size: B | Rev:

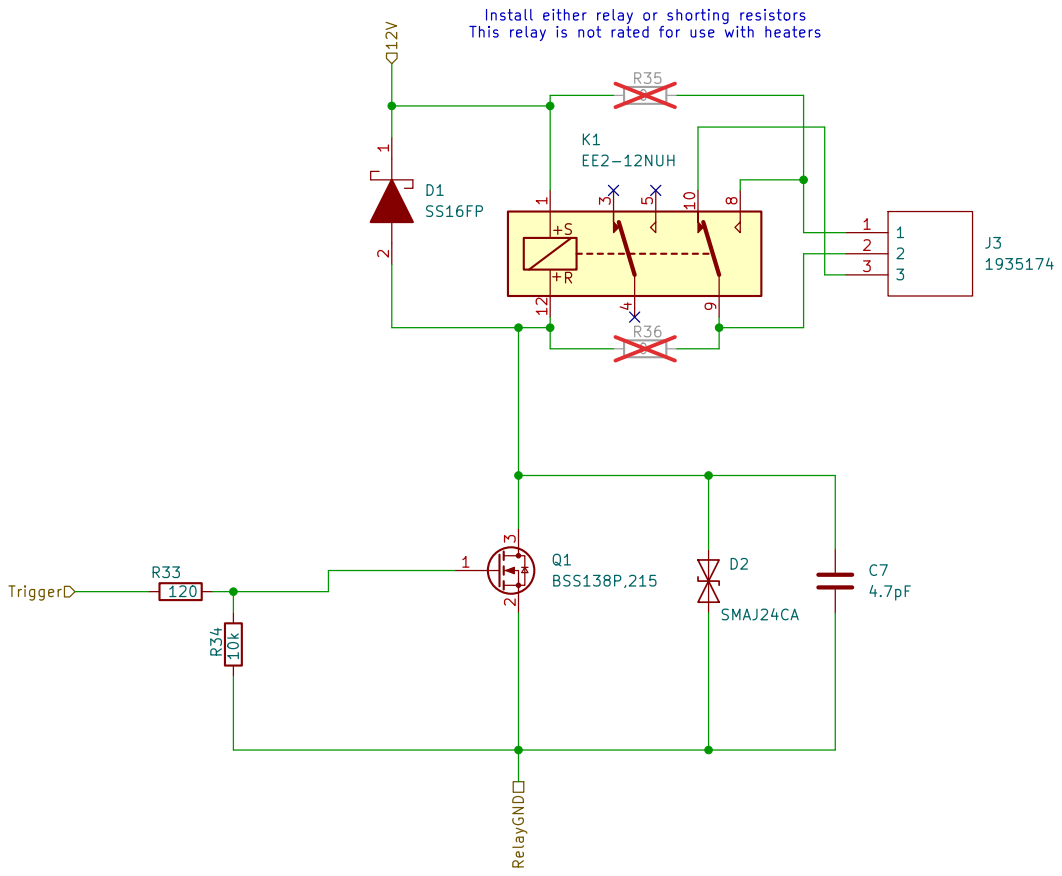
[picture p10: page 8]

Install either relay or shorting resistors
This relay is not rated for use with heaters

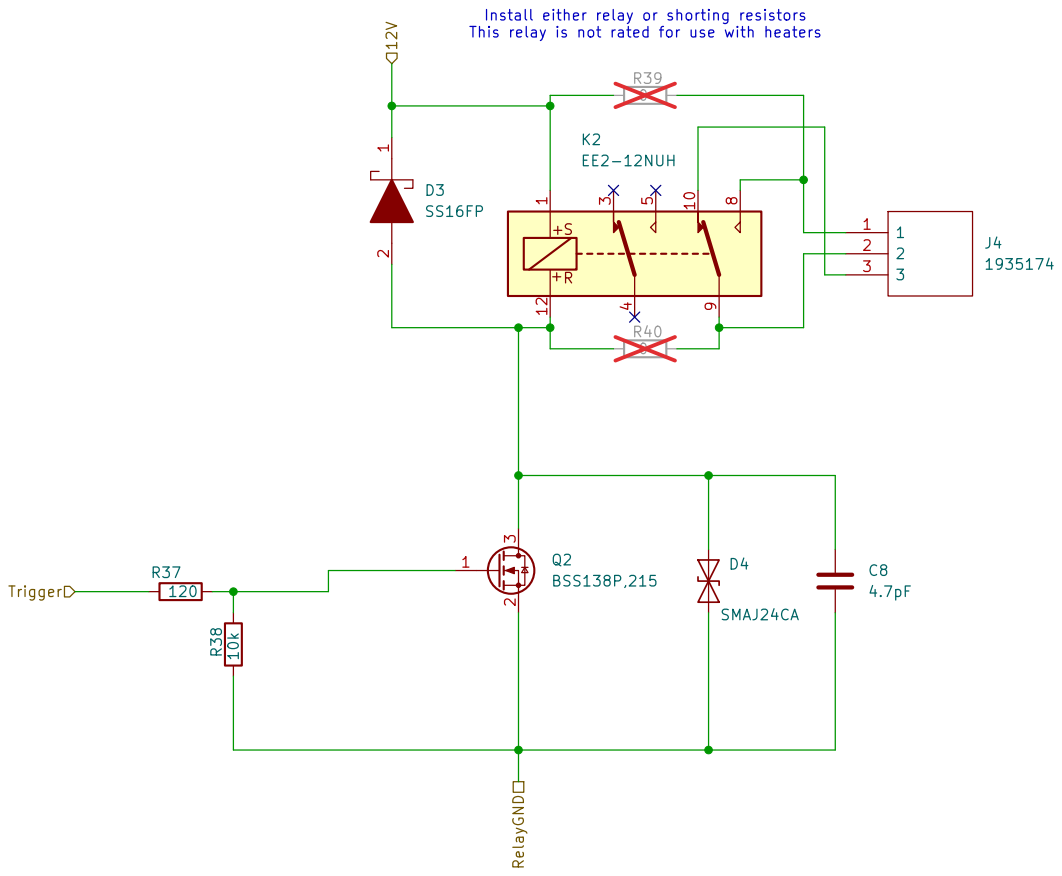
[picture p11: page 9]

Install either relay or shorting resistors
This relay is not rated for use with heaters

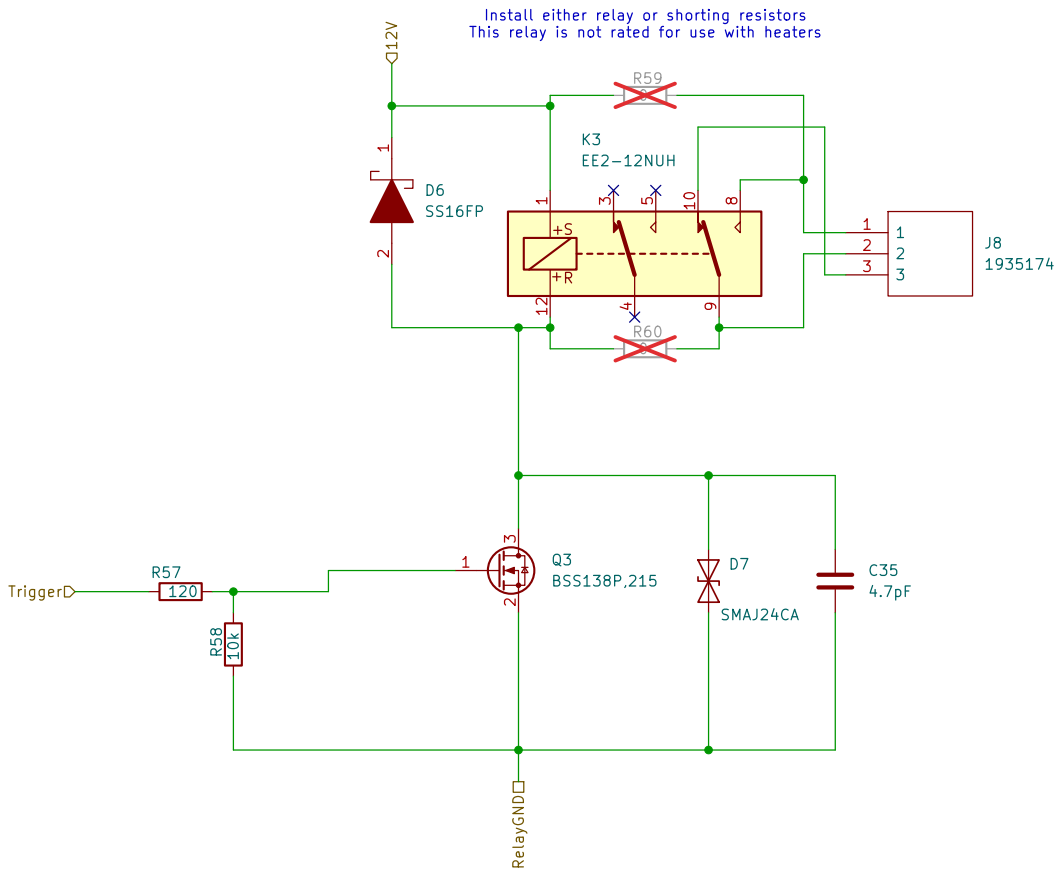
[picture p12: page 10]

Install either relay or shorting resistors
This relay is not rated for use with heaters

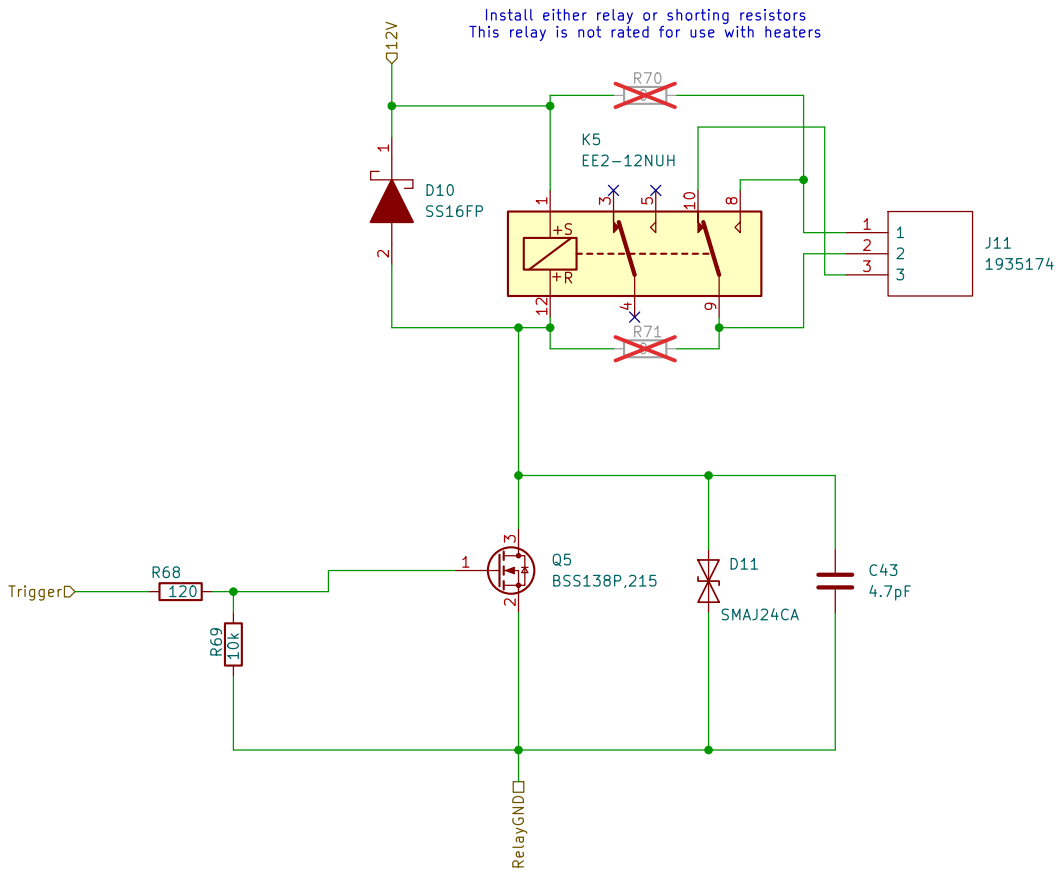
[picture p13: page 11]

Install either relay or shorting resistors
This relay is not rated for use with heaters

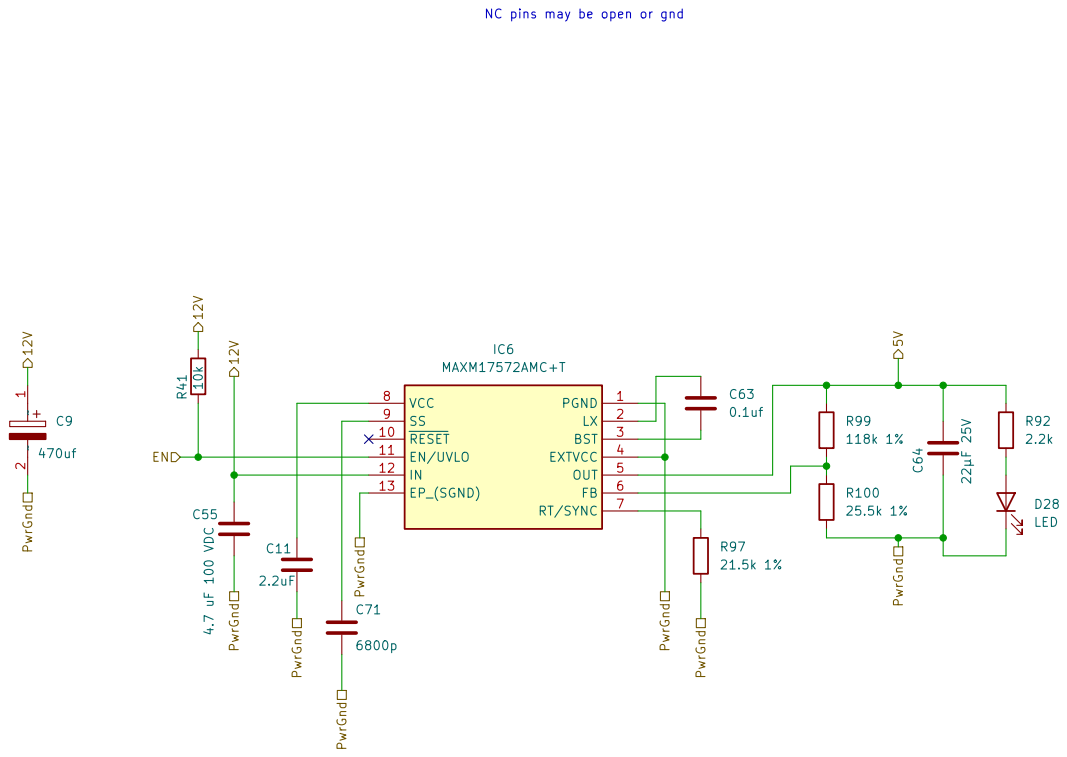
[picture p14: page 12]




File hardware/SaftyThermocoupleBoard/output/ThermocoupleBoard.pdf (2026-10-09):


Size: A4 | Rev:
KiCad E.D.A. 10.0.4 | Id: 1/2


Size: A | Rev:
KiCad E.D.A. 10.0.4 | Id: 2/2

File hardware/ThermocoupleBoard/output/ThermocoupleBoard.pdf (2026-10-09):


Size: A4 | Rev:
KiCad E.D.A. 10.0.4 | Id: 1/4




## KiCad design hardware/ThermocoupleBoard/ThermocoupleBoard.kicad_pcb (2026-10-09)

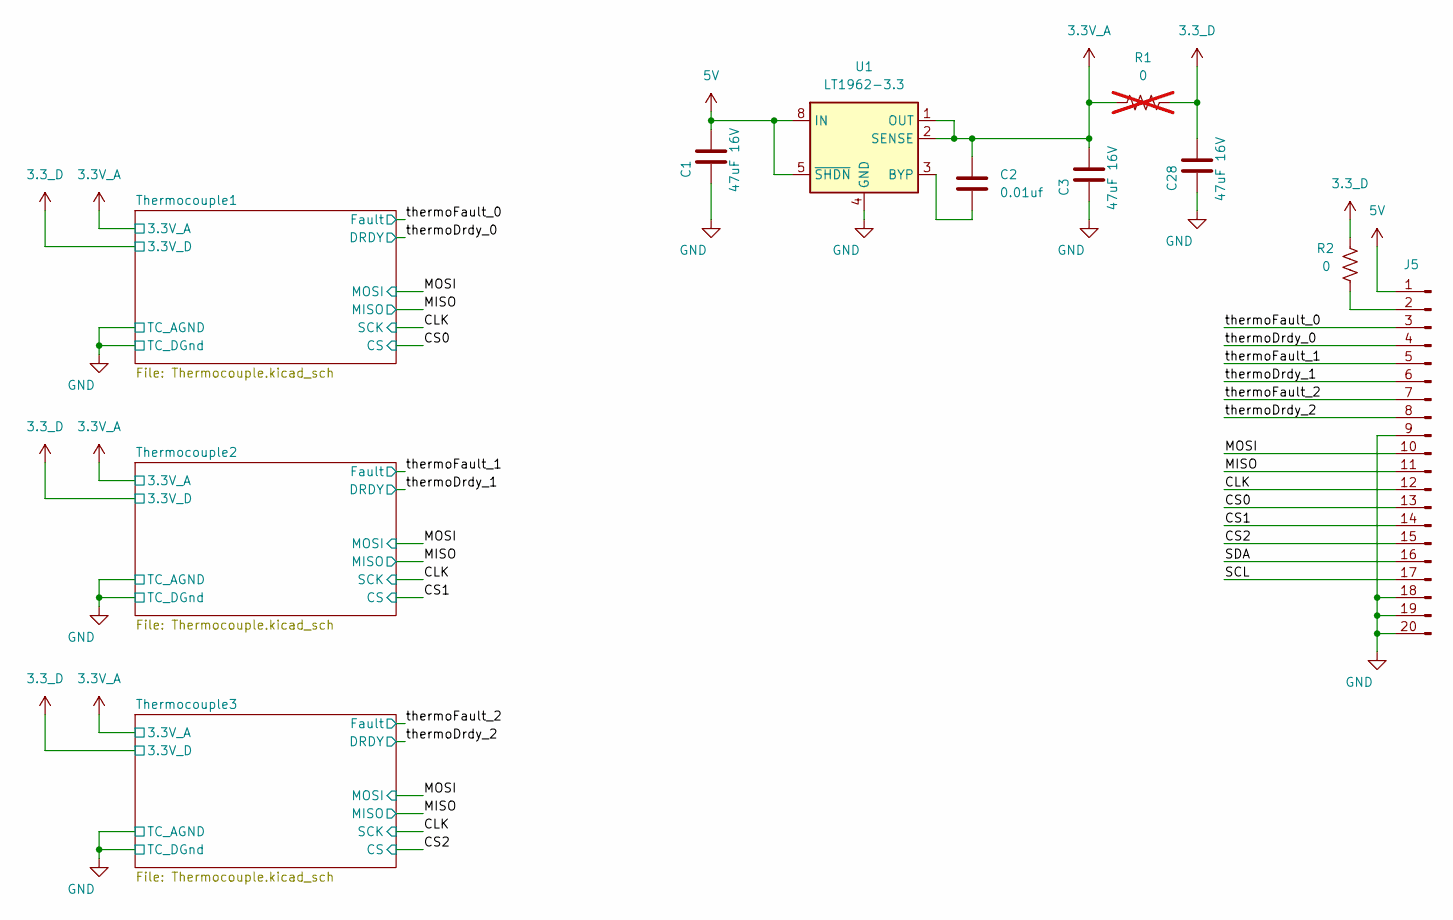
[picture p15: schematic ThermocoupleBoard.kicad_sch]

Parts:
C1, C3, C28: 47uF 16V; C_1210_3225Metric
C2: 0.01uf; C_0402_1005Metric
J5: Conn_01x20_Pin; PinHeader_1x20_P2.54mm_Horizontal
R1: 0; R_0402_1005Metric; not fitted
R2: 0; R_0402_1005Metric
U1: LT1962-3.3; MSOP-8_3x3mm_P0.65mm

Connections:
3.3V_A: C2.1, C3.2, R1.2, U1.1 (OUT), U1.2 (SENSE); also elsewhere on the board
3.3_D: C28.2, R1.1, R2.1; also elsewhere on the board
5V: C1.2, J5.1, U1.5 (~SHDN), U1.8 (IN)
/CLK: J5.12; also elsewhere on the board
/CS0: J5.13; also elsewhere on the board
/CS1: J5.14; also elsewhere on the board
/CS2: J5.15; also elsewhere on the board
/MISO: J5.11; also elsewhere on the board
/MOSI: J5.10; also elsewhere on the board
/SCL: J5.17
/SDA: J5.16
/thermoDrdy_0: J5.4; also elsewhere on the board
/thermoDrdy_1: J5.6; also elsewhere on the board
/thermoDrdy_2: J5.8; also elsewhere on the board
/thermoFault_0: J5.3; also elsewhere on the board
/thermoFault_1: J5.5; also elsewhere on the board
/thermoFault_2: J5.7; also elsewhere on the board
GND: C1.1, C3.1, C28.1, J5.9, J5.18, J5.19, J5.20, U1.4 (GND); also elsewhere on the board
unnamed: J5.2, R2.2
unnamed: C2.2, U1.3 (BYP)

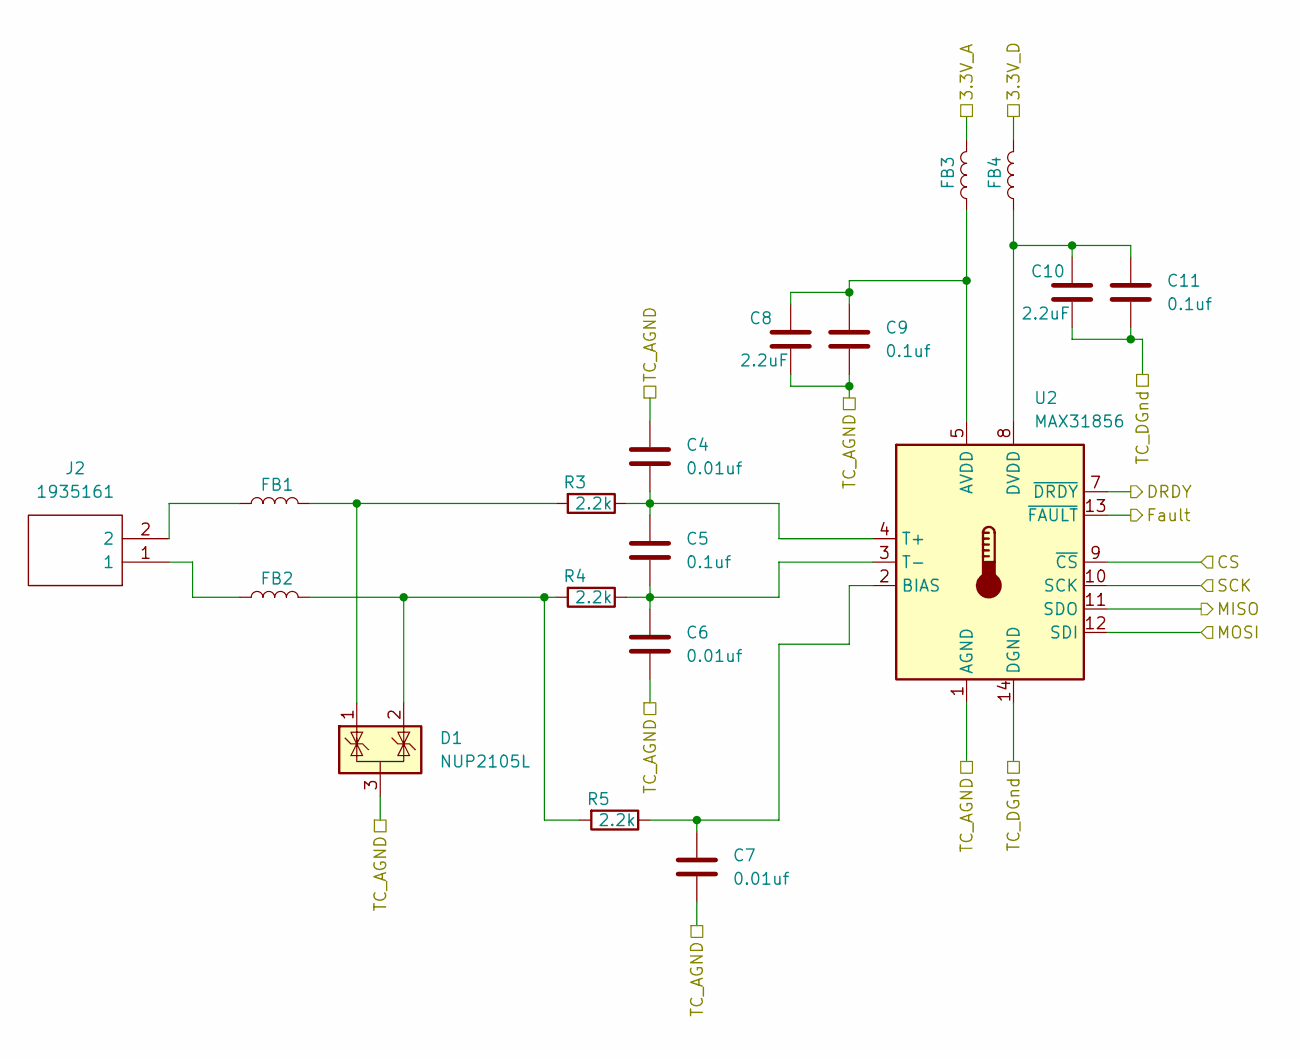
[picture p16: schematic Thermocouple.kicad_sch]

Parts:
C4, C6, C7: 0.01uf; C_0402_1005Metric
C5, C9, C11: 0.1uf; C_0402_1005Metric
C8, C10: 2.2uF; C_1206_3216Metric
D1: NUP2105L; SOT-23
FB1, FB2, FB3, FB4: 1.8k; L_0402_1005Metric_Pad0.77x0.64mm_HandSolder
J2: 1935161; Mouser Part Number 651-1935161
R3, R4, R5: 2.2k; R_0402_1005Metric
U2: MAX31856; TSSOP-14_4.4x5mm_P0.65mm

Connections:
3.3V_A: FB3.2; also elsewhere on the board
3.3_D: FB4.2; also elsewhere on the board
/CLK: U2.10 (SCK); also elsewhere on the board
/CS0: U2.9 (~CS); also elsewhere on the board
/MISO: U2.11 (SDO); also elsewhere on the board
/MOSI: U2.12 (SDI); also elsewhere on the board
/thermoDrdy_0: U2.7 (~DRDY); also elsewhere on the board
/thermoFault_0: U2.13 (~FAULT); also elsewhere on the board
GND: C4.1, C6.2, C7.2, C8.2, C9.2, C10.2, C11.2, D1.3 (A), U2.1 (AGND), U2.14 (DGND); also elsewhere on the board
unnamed: D1.1 (K), FB1.2, R3.2
unnamed: D1.2 (K), FB2.2, R4.2, R5.2
unnamed: FB1.1, J2.2
unnamed: FB2.1, J2.1
unnamed: C8.1, C9.1, FB3.1, U2.5 (AVDD)
unnamed: C7.1, R5.1, U2.2 (BIAS)
unnamed: C10.1, C11.1, FB4.1, U2.8 (DVDD)
unnamed: C4.2, C5.1, R3.1, U2.4 (T+)
unnamed: C5.2, C6.1, R4.1, U2.3 (T-)

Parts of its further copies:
C12, C14, C15, C20, C22, C23: 0.01uf; C_0402_1005Metric
C13, C17, C19, C21, C25, C27: 0.1uf; C_0402_1005Metric
C16, C18, C24, C26: 2.2uF; C_1206_3216Metric
D2, D3: NUP2105L; SOT-23
FB5, FB6, FB7, FB8, FB9, FB10, FB11, FB12: 1.8k; L_0402_1005Metric_Pad0.77x0.64mm_HandSolder
J3, J4: 1935161; Mouser Part Number 651-1935161
R6, R7, R8, R9, R10, R11: 2.2k; R_0402_1005Metric
U3, U4: MAX31856; TSSOP-14_4.4x5mm_P0.65mm

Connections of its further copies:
3.3V_A: FB7.2, FB11.2; also elsewhere on the board
3.3_D: FB8.2, FB12.2; also elsewhere on the board
/CLK: U3.10 (SCK), U4.10 (SCK); also elsewhere on the board
/CS1: U3.9 (~CS); also elsewhere on the board
/CS2: U4.9 (~CS); also elsewhere on the board
/MISO: U3.11 (SDO), U4.11 (SDO); also elsewhere on the board
/MOSI: U3.12 (SDI), U4.12 (SDI); also elsewhere on the board
/thermoDrdy_1: U3.7 (~DRDY); also elsewhere on the board
/thermoDrdy_2: U4.7 (~DRDY); also elsewhere on the board
/thermoFault_1: U3.13 (~FAULT); also elsewhere on the board
/thermoFault_2: U4.13 (~FAULT); also elsewhere on the board
GND: C12.1, C14.2, C15.2, C16.2, C17.2, C18.2, C19.2, C20.1, C22.2, C23.2, C24.2, C25.2, C26.2, C27.2, D2.3 (A), D3.3 (A), U3.1 (AGND), U3.14 (DGND), U4.1 (AGND), U4.14 (DGND); also elsewhere on the board
unnamed: D2.1 (K), FB5.2, R6.2
unnamed: D2.2 (K), FB6.2, R7.2, R8.2
unnamed: D3.1 (K), FB9.2, R9.2
unnamed: D3.2 (K), FB10.2, R10.2, R11.2
unnamed: FB5.1, J3.2
unnamed: FB6.1, J3.1
unnamed: FB9.1, J4.2
unnamed: FB10.1, J4.1
unnamed: C16.1, C17.1, FB7.1, U3.5 (AVDD)
unnamed: C15.1, R8.1, U3.2 (BIAS)
unnamed: C18.1, C19.1, FB8.1, U3.8 (DVDD)
unnamed: C12.2, C13.1, R6.1, U3.4 (T+)
unnamed: C13.2, C14.1, R7.1, U3.3 (T-)
unnamed: C24.1, C25.1, FB11.1, U4.5 (AVDD)
unnamed: C23.1, R11.1, U4.2 (BIAS)
unnamed: C26.1, C27.1, FB12.1, U4.8 (DVDD)
unnamed: C20.2, C21.1, R9.1, U4.4 (T+)
unnamed: C21.2, C22.1, R10.1, U4.3 (T-)

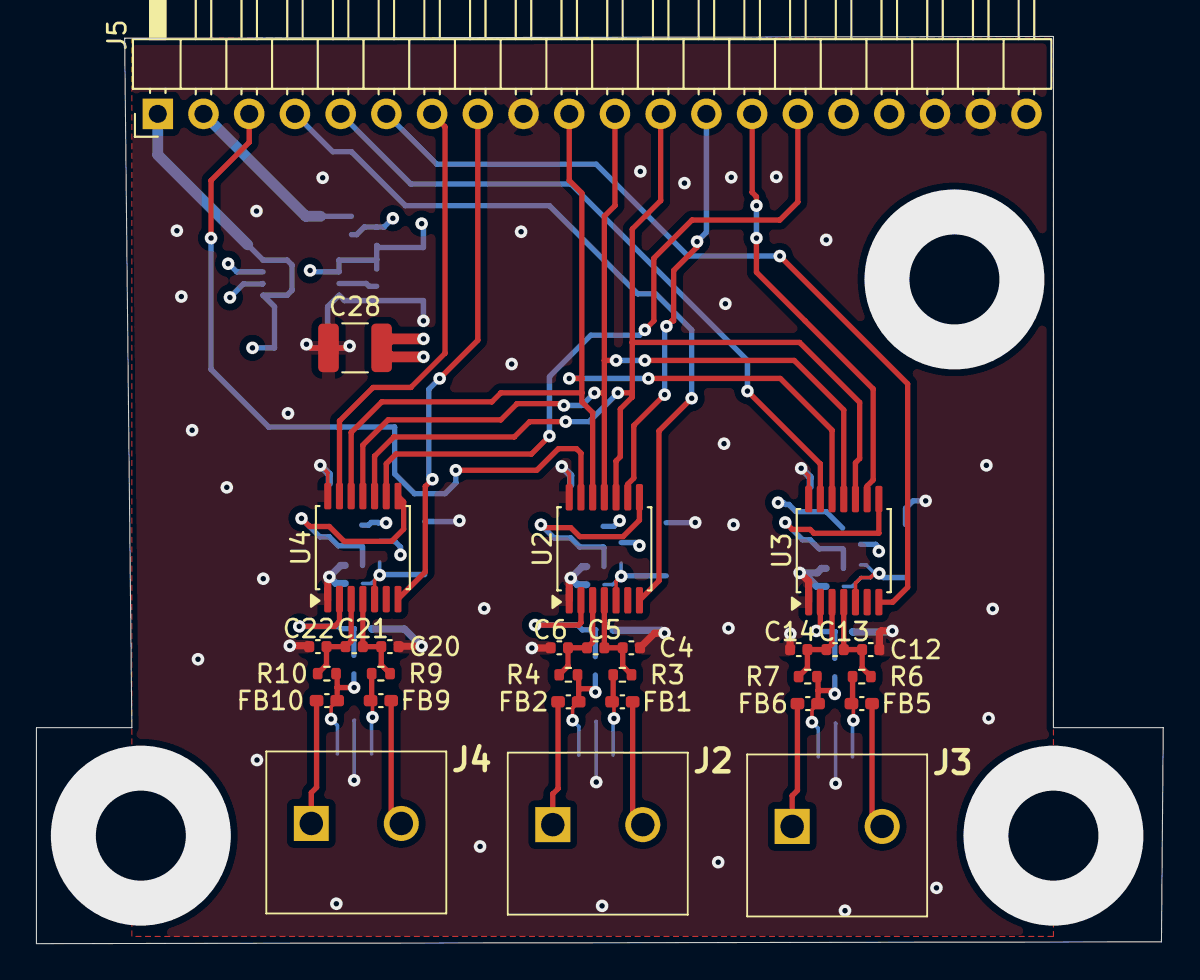
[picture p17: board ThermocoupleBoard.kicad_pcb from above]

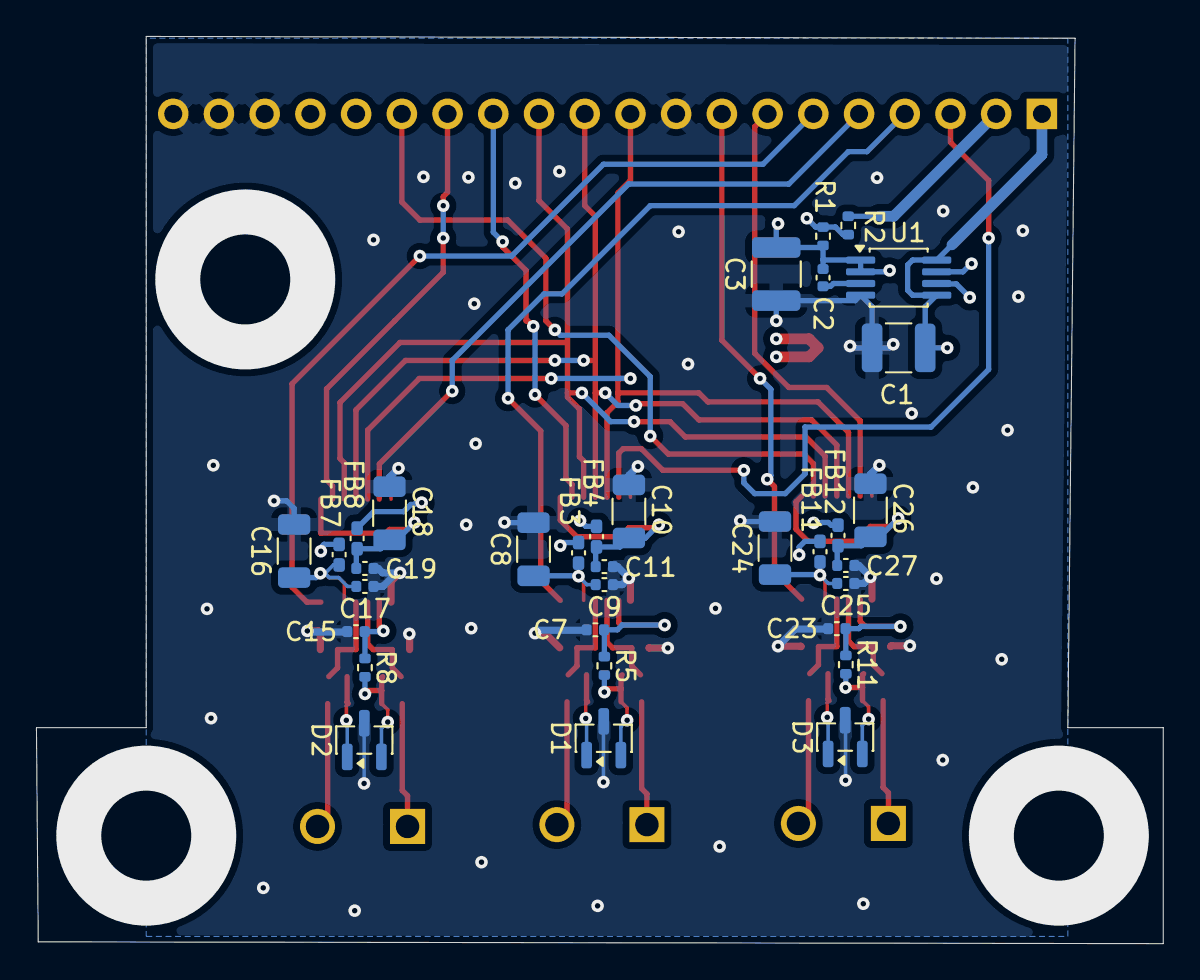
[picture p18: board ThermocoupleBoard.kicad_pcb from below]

Board: 4 copper layers, 62.6 x 50.4 mm, 62 parts (33 on the bottom side), 45 nets.

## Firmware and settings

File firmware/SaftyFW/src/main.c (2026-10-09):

// main.c -- SaftyFW entry point. Implements the boot sequence from
// docs/ARCHITECTURE.md section 5 in order; if this file and that section ever
// disagree, the doc is either stale (fix it in the same commit as any
// intentional change here) or this file has a bug.
//
//   1. GPIO6 -> output, driven LOW.        <- FIRST, before anything else
//   2. Watchdog enabled (1 s).
//   3. Read boot_reason; latch it.
//   4. Load config from flash; on CRC failure use safe defaults + set a flag.
//   5. Bring up spi_owner, adc_owner, uart_owner (non-blocking TX).
//   6. Probe the MAX31856. Failure is logged, not fatal.
//   7. Start tasks in priority order.
//   8. Enter GRACE for startup_grace_s (60 s): relay stays de-energized.
//   9. Enter ARMED. K4 may now be energized, iff no guard is tripped.
//
// This phase (TODO.md Phase 2, "Skeleton") implements steps 1-3 and 7 for
// real. Steps 4-6 and 8-9 are TODOs for Phases 3-9 -- see the TODO comments
// at each step below and TODO.md's own phase breakdown; this file does not
// pretend those phases are done.
#include <stdio.h> // snprintf, for the boot-time fatal-fault console banner (step 3c) -- see that block's own comment

#include "pico/stdlib.h"

#include "FreeRTOS.h"
#include "task.h"

#include "hardware/gpio.h" // permanent holdout: GPIO6-low is the literal first statement of main(), deliberately raw and ahead of hal_gpio (see relay_owner.h/.c) -- see firmware/hwAbstraction/README.md "Permanent holdouts"
#include "hardware/regs/timer.h" // TIMER_DBGPAUSE_BITS, see step 1b below -- permanent holdout, no hal_wdt/hal_scratch primitive covers this register
#include "hardware/timer.h" // timer_hw->dbgpause, see step 1b below -- permanent holdout, no hal_wdt/hal_scratch primitive covers this register
#include "hardware/watchdog.h" // permanent holdout: watchdog_caused_reboot()/watchdog_enable_caused_reboot() boot-reason reads and vApplicationStackOverflowHook()'s raw scratch[5] write are not expressible through hal_wdt.h/hal_scratch.h -- see firmware/hwAbstraction/README.md "Permanent holdouts"

#include "board_pins.h"
#include "boot_reason.h"
#include "hal_scratch.h" // HAL Phase 3 item 1 -- claims for every real scratch owner, see the block in main() below
#include "clear_trip_diag.h" // 2026-08-23 round 4, CLEAR_TRIP crash checkpoints, see its own header comment
#include "watchdog_overdue_diag.h" // 2026-08-23, the CLEAR_TRIP investigation's actual conclusion, see its own header comment
#include "startup_diag.h"
#include "config_store.h"
#include "max31856.h"
/* spi_owner.h's direct include is gone -- HAL Phase 1b routed the SPI0
 * bring-up used below through max31856_bus_init() (max31856.h), which
 * itself goes through interface/hal_spi.h / pico/spi/hal_spi_pico.c over
 * the same spi_owner.c body. */

#include "tasks/console_uart.h"
#include "tasks/current_task.h"
#include "tasks/discrete_task.h"
#include "tasks/link_task.h"
#include "tasks/log_task.h"
#include "tasks/relay_owner.h"
#include "tasks/safety_core.h"
#include "tasks/thermo_task.h"
#include "hal_uart_pico_internal.h"  // HAL Phase 1a: was tasks/uart_owner.h; moved+renamed to firmware/hwAbstraction/pico/uart/hal_uart_pico_internal.h
#include "tasks/update_task.h"
#include "tasks/watchdog_task.h"

#define SAFTYFW_WATCHDOG_TIMEOUT_MS 1000

// FreeRTOSConfig.h turns on configCHECK_FOR_STACK_OVERFLOW (2) and
// configUSE_MALLOC_FAILED_HOOK (1) unconditionally -- cheap insurance in a
// safety-relevant build, per that file's own comment -- which means the
// kernel requires these two hooks to exist at link time. Halting in place
// (same policy as configASSERT, FreeRTOSConfig.h) rather than resetting:
// resetting would let the watchdog mask a stack overflow or a heap
// exhaustion as an ordinary-looking reboot, which is exactly the kind of
// silent failure ARCHITECTURE.md section 4's boot_reason latching exists to
// avoid for guard trips -- these two deserve the same "stop and let a
// debugger see it" treatment, not fewer eyes on them.
void vApplicationStackOverflowHook(TaskHandle_t xTask, char *pcTaskName)
{
    (void)xTask;

    // DO NOT REMOVE THE WRITE BELOW AS DEAD WEIGHT. It is not decoration --
    // it is the ONLY reason the CLEAR_TRIP-reboots-the-Pico investigation
    // was ever solvable. Before it existed, a stack overflow on this
    // firmware was bit-for-bit indistinguishable from any other watchdog
    // reset: this hook disables interrupts and hangs (below), so
    // watchdog_task never runs again to leave its own diagnostic, and the
    // reboot that follows carries no evidence of what actually happened.
    // Two live suspects (safety_core_task, then log_task) were each
    // eliminated or confirmed ONLY once this write existed to name the
    // real one on the next boot. Removing it returns this firmware to that
    // blind state.
    //
    // 2026-08-23, the CLEAR_TRIP-reboots-the-Pico investigation's actual
    // mechanism: this hook disables interrupts and hangs, deliberately (see
    // the comment above), which means watchdog_task never runs again, the
    // unfed hardware watchdog resets the chip about a second later, and
    // -- until this write existed -- NO diagnostic of any kind survived:
    // scratch[5]'s overdue-checkin latch read magic_ok == false after a
    // reproduced crash, proving watchdog_task_fn() never even reached the
    // branch that would have written it. A stack overflow on this firmware
    // was, until now, indistinguishable from any other watchdog reset.
    //
    // This write closes that gap. It shares watchdog_hw->scratch[5] with
    // watchdog_overdue_diag_codec.c's own overdue-checkin format, tagged
    // with a DIFFERENT magic byte (0xE3 vs that format's 0xD9) so the two
    // never collide -- see watchdog_overflow_diag_t's own doc comment
    // (watchdog_overdue_diag_codec.h) for why sharing one register is
    // correct.
    //
    // CORRECTION, 2026-09-10 (opus review finding A): the paragraph that
    // used to sit here claimed "a stack overflow's interrupt-disable is
    // exactly what prevents watchdog_task from ever reaching its own write,
    // so the two events are mutually exclusive by construction." That is
    // false on this chip: FreeRTOSConfig.h sets configNUMBER_OF_CORES 2, and
    // taskDISABLE_INTERRUPTS() below silences only the CALLING core.
    // watchdog_task runs pinned to SAFTYFW_CORE_TRIP_PATH (watchdog_task.c),
    // while every other task -- including whichever one just overflowed
    // here -- runs pinned to SAFTYFW_CORE_LINK_PATH (link_task.c/log_task.c/
    // update_task.c). A stack overflow on the LINK core hangs only that
    // core; watchdog_task keeps running on the TRIP core, notices the hung
    // task missed its check-in, and DOES reach its own write. The mutual-
    // exclusion property this comment used to claim does not hold. What
    // actually protects THIS write now is watchdog_overdue_diag_mark()'s own
    // guard (watchdog_overdue_diag.c): it reads the register back first and
    // refuses to overwrite an already-latched fatal tag, so whichever of the
    // two writers gets here first always wins and is never clobbered by the
    // other. This write itself stays a plain, ungated MMIO store -- correct,
    // for the "stack may already be corrupted" reason given below.
    //
    // Deliberately NOT calling into watchdog_overdue_diag.c/_codec.c's own
    // functions: this hook may be running moments after the very stack
    // such a call would need has overflowed, so nothing beyond a plain MMIO
    // write is safe here -- no snprintf, no strlen, no function call beyond
    // this one register write. pcTaskName[0]/[1] are safe to read
    // regardless: FreeRTOS points pcTaskName at the task's own registered
    // name, a static string literal in .rodata (see every xTaskCreate()
    // call site in this codebase), never the corrupted stack itself. Two
    // bytes is enough to disambiguate every task this firmware currently
    // registers (current_task/discrete_task/link_task/log_task/
    // relay_owner/safety_core/thermo_task/update_task/watchdog_task all
    // differ in their first two characters) --
    // test_two_name_bytes_disambiguate_every_current_task in
    // test_watchdog_overdue_diag_codec.c is the regression guard for that
    // fact holding as tasks are added.
    //
    // The bit layout (magic byte in [31:24], name bytes in [23:16]/[15:8])
    // is kept in exact, hand-maintained sync with
    // watchdog_overflow_diag_decode() (watchdog_overdue_diag_codec.c) --
    // there is deliberately no shared encoder, for the same "cannot safely
    // call into another compilation unit here" reason.
    uint8_t name0 = 0u;
    uint8_t name1 = 0u;
    if (pcTaskName != NULL) {
        name0 = (uint8_t)pcTaskName[0];
        if (name0 != 0u) {
            name1 = (uint8_t)pcTaskName[1];
        }
    }
    // Deliberately a raw watchdog_hw->scratch[] write, NOT
    // hal_scratch_write_u32() -- see this hook's own comment above on why
    // no function call beyond this one register write is safe here. Slot 5
    // tag 0xE3 is still claimed (main(), before the scheduler starts) so
    // hal_scratch's runtime registry records this hook as slot 5's second
    // legitimate co-owner; the claim call and this write are two different
    // moments in two different execution contexts.
    watchdog_hw->scratch[5] = (0xE3u << 24) | ((uint32_t)name0 << 16) | ((uint32_t)name1 << 8);

    taskDISABLE_INTERRUPTS();
    for (;;) {
    }
}

void vApplicationMallocFailedHook(void)
{
    // 2026-09-09: same treatment, and for the same reason, as the stack-
    // overflow hook above -- until this line existed, a heap exhaustion on
    // this board disabled interrupts, hung, let the unfed 1 s watchdog
    // reset the chip, and left NOTHING behind: bit-for-bit
    // indistinguishable from any other watchdog reset, from a stack
    // overflow's own reset before that hook got its write, and from a
    // failed configASSERT. Shares watchdog_hw->scratch[5] with the other
    // three formats under its own magic byte (0xB4) -- see
    // watchdog_fatal_diag_t's doc comment (watchdog_overdue_diag_codec.h)
    // for why one register safely serves all of them.
    //
    // Raw MMIO write with a macro-built constant, not a function call, for
    // the same reason the overflow hook above states: the heap is already
    // exhausted here and the caller's context is not one to make
    // assumptions in. WATCHDOG_FATAL_MALLOC_WORD() is a macro precisely so
    // this stays one store.
    //
    // Records no payload beyond the kind: FreeRTOS's malloc-failed hook
    // takes no arguments at all -- it is never told the requested size --
    // so there is nothing further to record that would not require calling
    // into the heap implementation from inside a heap failure.
    watchdog_hw->scratch[5] = WATCHDOG_FATAL_MALLOC_WORD();

    taskDISABLE_INTERRUPTS();
    for (;;) {
    }
}

int main(void)
{
    // --- Step 1: GPIO6 low, before anything else touches the board. --------
    // The literal first statements of main(), ahead of even stdio/clock
    // bring-up. GPIO6 powers up as a floating input; a floating gate on Q4 is
    // an undefined coil state (docs/ARCHITECTURE.md section 5). Driving it
    // low first is the same discipline KilnFW applies to kiln_io_init's
    // relay-bits-before-direction ordering, and it is not a formality --
    // every millisecond between power-on and this line is a millisecond K4's
    // state is genuinely unknown.
    gpio_init(SAFTYFW_PIN_RELAY);
    gpio_put(SAFTYFW_PIN_RELAY, 0);      // set the output latch to LOW before...
    gpio_set_dir(SAFTYFW_PIN_RELAY, GPIO_OUT); // ...making the pin an output, so it is never briefly undriven-low/undriven-high

    // Console UART0 (GP16/GP17, debug probe bridge) as early as possible --
    // ahead of even stdio/watchdog/config, deliberately, so a hang or crash
    // anywhere below this line still leaves a boot banner on the wire. This
    // is the M0 liveness proof: a console that comes up before anything that
    // could go wrong has had a chance to. See console_uart.h and
    // docs/HARDWARE.md section 7b.
    console_uart_init();
    console_uart_puts("\r\n=== SaftyFW boot ===\r\n");

    // stdio/clocks: safe to bring up now that GPIO6 is settled. Needed for
    // SAFTYFW_ENABLE_USB_STDIO builds later (TODO.md Phase 2) and harmless
    // otherwise -- stdio_init_all() is a no-op if no stdio backend is
    // selected in CMakeLists.txt.
    stdio_init_all();

    // --- Step 1b: un-pause the hardware TIMER peripheral for debug halts. --
    // 2026-08-23, the DIAG-content-frozen investigation's actual root cause:
    // TIMER_DBGPAUSE (timer_hw->dbgpause, a register belonging to the TIMER
    // peripheral itself -- NOT watchdog_hw->ctrl's PAUSE_DBG0/DBG1/JTAG bits,
    // which only gate the watchdog's own countdown) resets to 0x7 on this
    // silicon: both DBG0 and DBG1 set, meaning the shared timer counter that
    // to_ms_since_boot(get_absolute_time())/time_us_64() read PAUSES the
    // instant either core is halted by a debugger. Confirmed on the bench:
    // dbgpause read 0x7, TIMERAWL held dead flat (507171us, matching the
    // frozen uptime_ms=507 every DIAG frame reported) across an 8s window,
    // reproduced from a clean flash+run with zero SWD contact afterward --
    // not an artifact of any particular read, an artifact of core 1 coming
    // up (multicore_launch_core1(), inside vTaskStartScheduler() below)
    // while a probe is attached and DBG1 is still at its power-on default.
    // Meanwhile xTaskGetTickCount() stayed healthy throughout, because
    // configTICK_CORE pins the FreeRTOS tick to core 0's own SysTick, a
    // core-local peripheral this register has no effect on -- so the board
    // looked completely alive on every FreeRTOS-tick-paced check while every
    // get_absolute_time()-based timestamp on it silently stopped.
    //
    // This firmware has never configured TIMER_DBGPAUSE (grepped the full
    // git history: never referenced before this line) -- the freeze is
    // RP2040 silicon default behaviour, not a regression, and it predates
    // this fix being visible only because DIAG frames never reached the ESP
    // before 2026-08-23's separate UART self-start-failure fix (uart_owner.c)
    // let anyone actually read a frozen uptime_ms in the first place.
    //
    // THE TRADE-OFF, stated on purpose rather than left implicit: clearing
    // this means get_absolute_time()/time_us_64() keep advancing even while
    // a core is halted mid-debug-session, instead of freezing in step with
    // it. That is a real loss for anyone who wanted debug-correlated timer
    // pausing (e.g. "does this ISR still fire while I'm single-stepping the
    // other core" style debugging). The trade is taken anyway: a debug probe
    // is attached to this board essentially continuously (JTAG/SWD is the
    // only sanctioned flashing path here, per docs/HARDWARE.md), so a timer
    // that silently stops whenever a core halts means every wall-clock
    // timestamp and every clock-based staleness check on a SAFETY processor
    // is unreliable during exactly the situations most likely to have a
    // probe attached -- worth more than debug-correlated pausing, which
    // nothing in this project depends on. safety_core.c's own clock_health.c
    // (added the same pass) is the belt to this fix's suspenders: it detects
    // a stalled get_absolute_time() explicitly and fails the two clock-based
    // staleness checks (context_valid, reboot_grace_active) closed even if
    // this register write is ever lost (a future SDK update, a differently
    // configured probe, RP2350 hardware with its own TICKS block, etc.) --
    // this fix should not be the ONLY thing standing between a stalled clock
    // and a guard that silently passes.
    //
    // Must run before vTaskStartScheduler() (step 8, below) brings up core 1
    // -- the whole point is that DBG1's pause-on-halt is already live the
    // instant core 1 exists to be halted.
    hw_clear_bits(&timer_hw->dbgpause, TIMER_DBGPAUSE_BITS);

    // --- hal_scratch claims for every real watchdog-scratch owner. ---------
    // HAL Phase 3 item 1 (docs/HW_ABSTRACTION.md "hal_scratch -- pico
    // watchdog-scratch registry"). Centralized here, once, before the first
    // real access (SAFTYFW_BOOT_STAGE() immediately below writes slot 6),
    // rather than one claim call per accessor module -- this is the single
    // list a future reviewer checks against the slot map in
    // startup_diag.h/hal_scratch.h's own header comments. Slot 4 is never
    // claimed here: hal_scratch_claim() refuses it outright, it belongs to
    // pico-sdk's watchdog_enable() below. Slot 5 gets TWO claims, same slot,
    // distinct tags -- its two legitimate, mutually-exclusive co-owners
    // (watchdog_overdue_diag.c's normal-operation latch and this file's own
    // vApplicationStackOverflowHook() above, which stays a raw MMIO write
    // for the reasons documented on that hook -- claiming it here is pure
    // bookkeeping, unrelated to how it actually writes). Return values are
    // intentionally ignored: a collision here is a build-time-invariant
    // programming error (two modules claiming the same (slot, tag)), not a
    // runtime condition this boot path needs to react to, and the registry
    // is advisory only (see hal_scratch.h's own "REGISTRY / UNIQUENESS"
    // note) -- nothing downstream consults these claims to gate a read or
    // write.
    (void)hal_scratch_claim(0u, "boot_reason", HAL_SCRATCH_TAG_NONE);
    (void)hal_scratch_claim(1u, "boot_reason", HAL_SCRATCH_TAG_NONE);
    (void)hal_scratch_claim(2u, "startup_diag", HAL_SCRATCH_TAG_NONE);
    (void)hal_scratch_claim(3u, "startup_diag", HAL_SCRATCH_TAG_NONE);
    (void)hal_scratch_claim(5u, "watchdog_overdue_diag", 0xD9u);
    (void)hal_scratch_claim(5u, "stack_overflow_hook", 0xE3u);
    // 2026-09-09: slot 5's two other legitimate co-owners -- see
    // watchdog_fatal_diag_t's doc comment (watchdog_overdue_diag_codec.h).
    // Both write raw MMIO (vApplicationMallocFailedHook() in this file;
    // configASSERT() in FreeRTOSConfig.h), same "claim here is bookkeeping
    // only" note as the two claims immediately above.
    (void)hal_scratch_claim(5u, "malloc_fail_hook", 0xB4u);
    (void)hal_scratch_claim(5u, "assert_hook", 0xA5u);
    (void)hal_scratch_claim(6u, "boot_stage", HAL_SCRATCH_TAG_NONE);
    (void)hal_scratch_claim(7u, "clear_trip_diag", HAL_SCRATCH_TAG_NONE);

    // --- Step 2: hardware watchdog, 1 s. ------------------------------------
    // pause_on_debug = true: hardcoded for now -- there is no release/debug
    // build distinction yet in this CMake project. TODO: add a build option
    // (e.g. SAFTYFW_RELEASE_BUILD) and flip this to false for it.
    // docs/ARCHITECTURE.md section 8 is explicit that a release build which
    // pauses on debug can have its watchdog silently disabled by an attached
    // probe -- "the one component where that matters".
    watchdog_enable(SAFTYFW_WATCHDOG_TIMEOUT_MS, true);
    SAFTYFW_BOOT_STAGE(SAFTYFW_BOOT_STAGE_WATCHDOG_ARMED);

    // --- Step 3: read boot_reason; latch it. --------------------------------
    // watchdog_caused_reboot()/watchdog_enable_caused_reboot() read
    // watchdog_hw->scratch[4], which watchdog_enable() above just wrote --
    // that write is a constant marker (not a per-boot value), so reading
    // these after enabling is equivalent to reading them before; what matters
    // is that watchdog_hw->reason (a separate, HW-latched register) was set
    // before any of this code ran. See src/boot_reason.c's header comment for
    // why scratch[0]/[1] (this firmware's own trip-reason latch) are
    // deliberately NOT scratch[4].
    saftyfw_boot_reason_t boot_reason =
        boot_reason_read(watchdog_caused_reboot(), watchdog_enable_caused_reboot());

    // TODO (Phase 8): report boot_reason (including, if trip_reason_valid,
    // "watchdog reset while tripped on <reason>") in the diagnostic frame --
    // ARCHITECTURE.md section 4: "A safety processor silently
    // watchdog-looping presents as a working system with mysterious
    // intermittent trips -- that bit is how you find it." Until log_task/
    // link_task have real bodies (Phase 7/8) there is nowhere to report it
    // to, so it is read and preserved here but not yet surfaced.
    (void)boot_reason;

    // Once this boot has read and (eventually) reported the latched trip
    // reason, clear it so an unrelated future reset does not re-report a
    // stale one. Safe to do unconditionally: boot_reason above already holds
    // whatever this boot needs.
    boot_reason_clear_trip();
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

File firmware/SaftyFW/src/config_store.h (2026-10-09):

// config_store.h -- the safety processor's versioned, CRC'd configuration
// record. TODO.md Phase 9's "Config store: versioned, CRC'd, safe defaults,
// calibration_missing flag" and "Config writes refused while ARMED".
//
// Deliberately the SAME discipline as bootloader/metadata.h: a small
// append-only log of fixed-size, magic+CRC'd records inside one flash
// sector, "scan every slot, keep the highest seq among those whose own CRC
// validates" to find the current record, safe defaults (never a hard
// failure) when nothing in the sector validates. See metadata.h's own header
// comment for why an append-only log, not "two copies alternately
// overwritten", is the only scheme that is actually safe on NOR flash within
// a single erase-granularity sector.
//
// Split the same way metadata.h/.c vs bootloader/main.c and
// src/tasks/update_task.c are split: this file (config_store.c) is pure --
// no RTOS, no pico-sdk, no direct flash I/O, operates only on caller-supplied
// buffers -- so it is host-testable exactly like metadata.c
// (test/test_config_store.c). The real flash reads/writes, the ARMED check
// against relay_owner, and the tc_type/calibration_missing getters main.c
// and future callers actually use live in config_store_flash.c, which is
// NOT host-tested for the same reason update_task.c and bootloader/main.c
// are not: it needs a real RP2040 (XIP-mapped reads, flash_safe_execute()).
//
// --- Format version 2 (this pass) ------------------------------------------
//
// Version 1 held only `tc_type`, `calibration_missing` and `ct_cal[3]` in a
// 256 B record (16 slots/sector) -- nowhere near enough room for
// docs/CONFIG_REFERENCE.md sections 1-5's full commissioning surface. This
// pass:
//
//   - Grows CONFIG_STORE_RECORD_LEN 256 -> 512 B (8 slots/sector instead of
//     16 -- still ample, since a record is written only at commissioning,
//     not at runtime; docs/COMMISSIONING.md section 1.1).
//   - Adds every field in CONFIG_REFERENCE.md sections 1-5.
//   - Adds `fields_set`, a bitmask of CONFIG_STORE_SET_* flags marking which
//     of the handful of fields that have NO safe compiled-in default have
//     actually been commissioned. CONFIG_REFERENCE.md section 7 is explicit
//     that "no default may be a guess dressed as a value" -- for
//     `tc_source`, `borrowed_zone_index`, `tc_placement_mode`,
//     `abs_max_temp_c`, `ct_channel_map`, `max_rate_c_per_min` and
//     `mains_voltage_v`, every representable numeric value (including 0,
//     which is a perfectly plausible temperature or a deliberate "rate
//     limit off") is a value someone could have meant. A sentinel value
//     collides with that; a separate bit cannot, which is why this module
//     uses an explicit "is this set" bit per field rather than trying to
//     reserve a magic number out of each field's own range. Any consumer
//     that reads one of these fields MUST check the corresponding
//     CONFIG_STORE_SET_* bit before trusting the value; the raw bytes when
//     the bit is clear are documented in config_store_default()'s comment
//     but are not a promise -- only the bit is authoritative.
//     `max_rate_c_per_min` is a partial exception since 2026-09-05: the
//     compiled RECORD now carries CONFIG_STORE_DEFAULT_MAX_RATE_C_PER_MIN
//     (2x the fastest rising built-in-profile ramp) as its at-rest value
//     instead of a bare 0.0f. That does not make it an armed default,
//     though -- safety_core.c's safety_core_load_guard_cfg() (around lines
//     393-394) still forces the value the guard actually runs with to 0.0f
//     (S8 off) unless CONFIG_STORE_SET_MAX_RATE_C_PER_MIN has been set
//     through commissioning, so the "no safe compiled-in ARMED default"
//     rule this paragraph describes is otherwise unchanged for this field.
//   - Three-outcome load in config_store_unpack(), mirroring the discipline
//     KilnFW's NVS loaders use (see e.g. App/drivers/http/zones_http.c):
//       * stored format_version == CONFIG_STORE_FORMAT_VERSION (2): load
//         normally.
//       * stored format_version == 1 (the only older version that has ever
//         existed): migrate forward. `tc_type`, `calibration_missing`
//         (forced true regardless of what v1 held -- see below) and
//         `ct_cal[3]` are preserved; everything new is defaulted via
//         config_store_default(). `calibration_missing` STAYS true because a
//         migrated record was never commissioned against the new fields --
//         setting it false here would tell every guard added in this pass
//         "the operator confirmed these" when nobody ever did.
//       * stored format_version > CONFIG_STORE_FORMAT_VERSION (a future
//         record read by older/this firmware): REFUSE. Returns false, same
//         as a CRC failure, so the caller falls back to
//         config_store_default(). This is deliberately NOT "best effort
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

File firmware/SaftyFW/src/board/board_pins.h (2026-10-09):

// board_pins.h -- the RP2040 GPIO/ADC map for A1 on the kilnCtl main board.
// Single source of truth so no task file re-derives a pin number from memory.
// Traced and verified in docs/HARDWARE.md section "Pico I/O map" (also ARCHITECTURE.md
// section 3's module table) -- if this disagrees with either, the docs win and this
// file is wrong.
//
// Deliberately a plain header, not a driver: it holds only pin numbers, not
// initialisation code, so every hardware-owner task can include it without
// pulling in another task's setup.
#ifndef SAFTYFW_BOARD_PINS_H
#define SAFTYFW_BOARD_PINS_H

// --- SPI0: MAX31856 thermocouple ADC (spi_owner) ---------------------------
#define SAFTYFW_PIN_SPI0_MISO   0   // GPIO0, SPI0 RX from the MAX31856
#define SAFTYFW_PIN_SPI0_CS0    1   // GPIO1, MAX31856 ~CS, active low, driven as plain GPIO
#define SAFTYFW_PIN_SPI0_SCK    2   // GPIO2, SPI0 SCK
#define SAFTYFW_PIN_SPI0_MOSI   3   // GPIO3, SPI0 TX

// --- UART1: the isolated link to the ESP (uart_owner / link_task) ----------
// NEVER referenced from safety_core.c or relay_owner.c -- see the CI grep
// check in tools/check_isolation.ps1.
// Isolated via U6 (ADuM1201WT digital isolator, non-inverting) as of
// 2026-08-25; previously via a TCMT1109 optocoupler pair (U2/U3, R7/R12/R15).
#define SAFTYFW_PIN_UART1_TX    4   // GP4, PicoTx -> U6 VIA (pin 7) -> U6 VOA (pin 2) -> ESP RX (GPIO4)
#define SAFTYFW_PIN_UART1_RX    5   // GP5, PicoRx <- U6 VOB (pin 6) <- U6 VIB (pin 3) <- ESP TX (GPIO5)

// --- The safety actuator (relay_owner). The ONLY code that may write this. -
#define SAFTYFW_PIN_RELAY       6   // GPIO6, saftyRelay -> Q4 gate -> K4 coil. High = energized.

// --- I2C0: wired to J7 but nothing answers today. Left uninitialised. ------
#define SAFTYFW_PIN_I2C0_SDA    7   // GPIO7
#define SAFTYFW_PIN_I2C0_SCL    8   // GPIO8

// --- Discretes (discrete_task) ----------------------------------------------
// GPIO9: ACTIVE HIGH for stop. R10 1k pull-up + C3 noise cap; normally-closed
// contact to GND_Safty, so LOW = healthy, HIGH = pressed/broken/unfitted.
// docs/HARDWARE.md section 5 forbids inverting this in firmware.
#define SAFTYFW_PIN_ESTOP       9
#define SAFTYFW_PIN_MAIN_FAULT  10  // GPIO10, U1 collector, active low

// --- Thermocouple front end (thermo_task, via spi_owner) -------------------
#define SAFTYFW_PIN_THERMO_FAULT 11 // GPIO11, MAX31856 ~FAULT, active low
#define SAFTYFW_PIN_THERMO_DRDY  12 // GPIO12, MAX31856 ~DRDY, active low, real IRQ (Phase 3)

// --- Current sense (current_task, via adc_owner) ----------------------------
// RP2040 SAR ADC input numbers, not GPIO numbers -- adc_select_input() takes
// these directly. GPIO26/27/28 must still be adc_gpio_init()'d (ARCHITECTURE.md
// section 8: "adc_gpio_init() disables the digital functions").
#define SAFTYFW_PIN_ADC0_GPIO    26 // GPIO26, ADC0, Current1
#define SAFTYFW_PIN_ADC1_GPIO    27 // GPIO27, ADC1, Current2
#define SAFTYFW_PIN_ADC2_GPIO    28 // GPIO28, ADC2, Current3
#define SAFTYFW_ADC_CH_CURRENT1  0
#define SAFTYFW_ADC_CH_CURRENT2  1
#define SAFTYFW_ADC_CH_CURRENT3  2
// ADC3 (GPIO29) reads VSYS/3 on a standard Pico -- USELESS here, VSYS is
// unconnected on this board (docs/HARDWARE.md section 6). Do not sample it.
// ADC4 is the internal die temperature sensor -- a free sanity check
// (ARCHITECTURE.md section 8), not part of this phase's skeleton.

// --- Console UART0, debug-probe bridge only (see docs/ARCHITECTURE.md sec 1)
// UART1 is taken by the isolated link, so the console/RTT-adjacent bench path
// uses UART0 on the one free pin pair this board has.
//
// CORRECTED 2026-08-21: these two were swapped relative to the silicon.
// RP2040 IO_BANK0 funcsel tables (pico-sdk
// src/rp2040/hardware_regs/include/hardware/regs/io_bank0.h) are explicit:
// GPIO16's funcsel 2 is UART0_TX, GPIO17's funcsel 2 is UART0_RX -- there is
// no funcsel on GPIO16 that produces UART0_RX or vice versa, so the Pico
// cannot be configured the other way regardless of what a #define says. This
// matches docs/HARDWARE.md section 7b's table (GP16 -> probe RX / Pico
// UART0 TX, GP17 -> probe TX / Pico UART0 RX), which was already correct;
// only this header disagreed with it.
#define SAFTYFW_PIN_UART0_TX     16 // GP16, Pico UART0 TX -> probe's RX
#define SAFTYFW_PIN_UART0_RX     17 // GP17, Pico UART0 RX <- probe's TX
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

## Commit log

2026-10-09 Release v1.0.0-pre.1
    Files identical to main commit bf9ddea296ad0132b12f2f163e04b6985845763e (tag v1.0.0-pre.1).
    Single-parent release commit: release history holds only release snapshots.
    [4.0inch_48P_0.8mm.PcbLib, 5V_Regulator.kicad_sch, CurrentSense.kicad_sch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]
2026-10-09 Release v1.0.0-pre.2
    Full non-Fast run_all_checks on dev tip fb236ec4 (tree of 129586d4): 186 passed, 0 skipped, 0 failed. Includes profile save mutex and web-commission node leak fix.
    Files identical to main commit 129586d4fd82f4fb34e9960b9f329855f292520c (tag v1.0.0-pre.2).
    [partitions.csv]
2026-10-13 Release v1.0.0-pre.3
    Bench functional test PASS on origin/main 5098a13164f9: ESP fw_build Oct 13 2026 02:12:48Z running app, Pico kilnlink v18, health OK, heap internal min_free 15675 B, relay toggle OK, short firing OK, LCD dashboard OK
    Files identical to main commit 5098a13164f9ebc9b8edae8fbf47b875c01b2bed (tag v1.0.0-pre.3).

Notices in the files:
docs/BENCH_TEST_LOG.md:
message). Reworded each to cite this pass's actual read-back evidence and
